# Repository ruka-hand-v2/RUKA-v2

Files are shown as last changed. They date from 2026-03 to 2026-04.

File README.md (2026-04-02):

<h1 align="center" style="font-size: 2.0em; font-weight: bold; margin-bottom: 0; border: none; border-bottom: none;">RUKA-v2: Tendon Driven Open-Source Dexterous Hand with Wrist and Abduction for Robot Learning</h1>

##### <p align="center"> [Xinqi Liu<sup>*2</sup>](https://www.linkedin.com/in/xinqi-liu-889256299/), [Ruoxi Hu<sup>*1</sup>](https://www.linkedin.com/in/sissi-h-013288321/), [Alejandro Ojeda Olarte<sup>1</sup>](https://aojedao.github.io/Portfolio/), [Zhuoran Chen<sup>2</sup>](https://www.linkedin.com/in/zhuoran-chen-90a18a251/), [Kenny Ma<sup>1</sup>](https://kmang0.github.io/KMAWeb/), [Charles Cheng Ji<sup>1</sup>](https://charlesji.com/), [Lerrel Pinto<sup>1</sup>](https://lerrelpinto.com), [Raunaq Bhirangi<sup>1</sup>](https://raunaqbhirangi.github.io/), [Irmak Guzey<sup>1</sup>](https://irmakguzey.github.io/)</p>
##### <p align="center"><sup>1</sup>New York University&emsp;<sup>2</sup>New York University Shanghai</p>
##### <p align="center"><sup>*</sup>Equal contribution</p>

<p align="center">
  
 </p>

#####
<div align="center">
     &ensp;
     &ensp; 
     &ensp;
    
</div>

#####

## Installation
Download the repo, create the conda environment, install requirements and install the `ruka_hand` package.
```
git clone --recurse-submodules https://github.com/ruka-hand-v2/RUKA-v2
cd RUKA-v2
conda env create -f environment.yml
conda activate ruka_hand
pip install -r requirements.txt
pip install -e .
```

### Connecting RUKA-v2
Connect the RUKA-v2 hand to your workstation using a USB cable. Then, identify which port the USB is connected to. You can do this by plugging and unplugging the hand while observing the changes in the output of `ls /dev/ttyUSB*`. The port that appears when you plug in the hand corresponds to that hand (left or right).
Update the `USB_PORTS` dictionary in `ruka_hand/utils/constants.py` accordingly, e.g., `USB_PORTS = {"left": "/dev/ttyUSB0", "right": "/dev/ttyUSB1"}`.

You can try moving the motors to the reset position by running:
```
python scripts/reset_motors.py --hand_type <right|left>
```
If this moves the intended hand then it means that the initial software is completed!

**NOTE:**
If you get an error saying that 
```
serial.serialutil.SerialException: [Errno 13] could not open port /dev/ttyUSB0: [Errno 13] Permission denied: '/dev/ttyUSB0'
```
You might need to run following commands to add your user to `dialout` group and reboot the machine for it to take effect.
```
sudo usermod -aG dialout $USER
sudo reboot
```

### Calibrating Motor Ranges
Since RUKA-v2 is a tendon-driven hand, cable tensions can vary between different builds. To ensure consistency across builds, we provide a calibration script that determines the motor ranges by finding the fully curled finger bound and the in-tension bound (finger is fully open and the tendon is in tension).
Run the following command to save the motor limits to `RUKA/motor_limits/<left|right>_<tension|curl>_limits.npy`:  
```
python calibrate_motors.py --hand-type <left|right>
```
These motor limits are later used in `ruka_hand/control/hand.py`.

During calibration, you will be prompted to move the joints individually using the ↑/↓ keys to increase or decrease the motor commands, and to press enter when a desired positon is reached. Make sure to identify which motor is moved and ensure that the string is tensioned when moving to the open position. 

When moving joints, we sometimes observe that the knuckle joints don't fully curl. If you notice this behavior (for example, the index finger not fully curling despite changing the motor command, please gently push the finger to complete the curl.

After running the calibration, execute `python scripts/reset_motors.py --hand-type <right|left>`. This should move the fingers to a fully open position, with the tendons tensioned but the fingers remaining extended.

## Teleoperation

We provide scripts to teleoperate RUKA-v2 using Mediapipe
 ```
  python teleop_mediapipe.py
  ```
And we provide controllers in `ruka_hand/control/controller_retarget.py` that can be used to teleoperate RUKA-v2 using the [Oculus headset](https://www.meta.com/quest/quest-3/). 

## Franka-Teach
We provide code for teleoperating the RUKA-v2 mounted on a 7-DOF Franka Arm with single arm and bimanual setups using Open-Teach in the submodules `franka-teach-single` and `franka-teach-bimanual`, please refer to documentation in the [Franka-Teach](https://github.com/pianapolataa/Franka-Teach/blob/main/README.md) submodules.

## BAKU
We provide code for training your own visual BC policy with RUKA-v2 using BAKU in the submodule `BAKU`. Please refer to documentation in the [BAKU](https://github.com/pianapolataa/BAKU/blob/main/Instructions.md) submodule.

## Attachable Encoders
For the attachable encoders setup and data collection, please see the [Attachable Encoders README](ruka_encoders/README.md).

**Quick Start Commands:**
```bash
python calibration/recalibrate_limits.py --serial-port /dev/ttyACM0 --hand right
python calibration/extract_filtered_limits.py
python data_collection/random_joint_generator.py --points-per-joint 15 --wait-time 1.5
```

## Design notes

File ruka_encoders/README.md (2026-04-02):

# RUKA Encoders (v2)

This directory contains the firmware, calibration tools, and data collection scripts for the magnetic angle sensors (AS5600) used on the RUKA hand. These tools are designed to map raw sensor readings to physical motor positions and analyze tracking performance.

---

## 📂 Directory Structure

### 1. [firmware/](firmware/)
Contains the code that runs on the microcontroller side to read the AS5600 sensors and stream data to a host PC.
- **`Microcontroller_AS5600.ino`**: Arduino/ESP32 firmware that reads multiple sensors via I2C using a TCA9548A multiplexer and outputs degree values over Serial.

### 2. [calibration/](calibration/)
Contains tools for defining the relationship between motor ticks and sensor degrees.
- **`recalibrate_limits.py`**: An interactive script that moves each motor to its limits and prompts for manual joint movement to capture absolute physical boundaries.
- **`extract_filtered_limits.py`**: Processes calibration logs to generate a statistical "Ground Truth" mapping in a json format.
- **`manually_filtered_paper_limits.json`**: The reference configuration file containing the finalized motor-to-sensor mappings and limit bounds.

### 3. [data_collection/](data_collection/)
Contains automated scripts for testing the sensors and capturing synchronized motor/sensor data.
- **`random_joint_generator.py`**: Executes a sequence of random movements for each joint within the safe bounds defined in the calibration JSON and creates a csv file with the motor and sensor data.

---

## ⚙️ Workflow & Usage

Follow these steps to set up and use the encoder system:

### Step 1: Flash the Firmware
Upload the [Microcontroller_AS5600.ino](firmware/Microcontroller_AS5600.ino) to your microcontroller. Ensure all sensors are connected via the I2C multiplexer as expected by the code.

### Step 2: Capture Physical Limits
Run the interactive calibration script to capture the range of motion for each joint:
```bash
python calibration/recalibrate_limits.py --serial-port /dev/ttyACM0 --hand right
```
*Note: This will save CSV logs and a preliminary JSON to the `recalibrate_limits_logs/` folder.*

### Step 3: Finalize the Mapping
Run the extractor on your calibration logs to generate a noise-filtered JSON reference:
```bash
python calibration/extract_filtered_limits.py
```
*Note: This will default to reading logs from calibration/recalibrate_limits_logs/ and outputting to calibration/manually_filtered_paper_limits.json.*

### Step 4: Run Automated Tests
Use the filtered JSON to run a bounded random movement sequence and log the tracking performance:
```bash
python data_collection/random_joint_generator.py --points-per-joint 15 --wait-time 1.5
```
*Note: This will default to using the JSON in calibration/ and saving new logs to data_collection/random_generator_logs/.*

---

## 🛠 Hardware Dependencies
- **Sensors**: AS5600 Magnetic Encoders and holders.
- **Robot**: RUKA v2 Hand.
- **Microcontroller**: ESP32 or Arduino ESP32.
- **I2C Multiplexer**: TCA9548A with Qwiic connectors.
- **Communication**: USB-C cable.

For hardware maintenance or sensor replacement instructions, refer to the [Disassembly.md](Disassembly.md) guide.

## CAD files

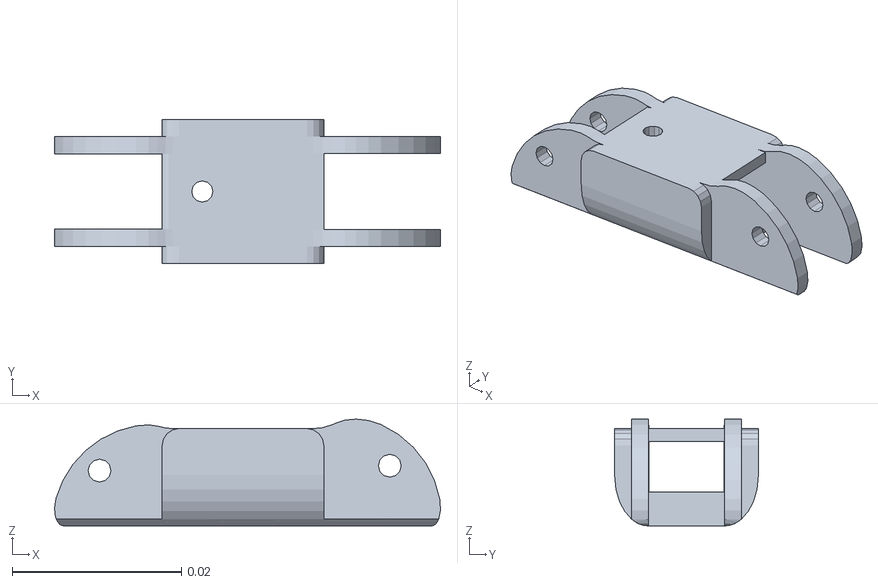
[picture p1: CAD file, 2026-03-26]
assets_v1/ruka/meshes/Middle_MCP.STL
0.0456 x 0.017 x 0.0126

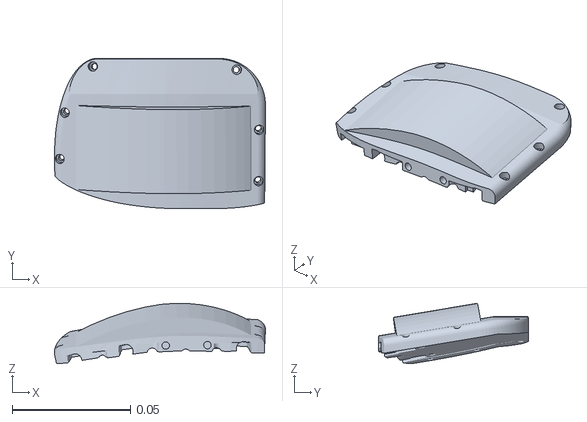
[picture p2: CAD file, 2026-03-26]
rukav2_sim/assets/backhand.stl
0.0891 x 0.0635 x 0.0255

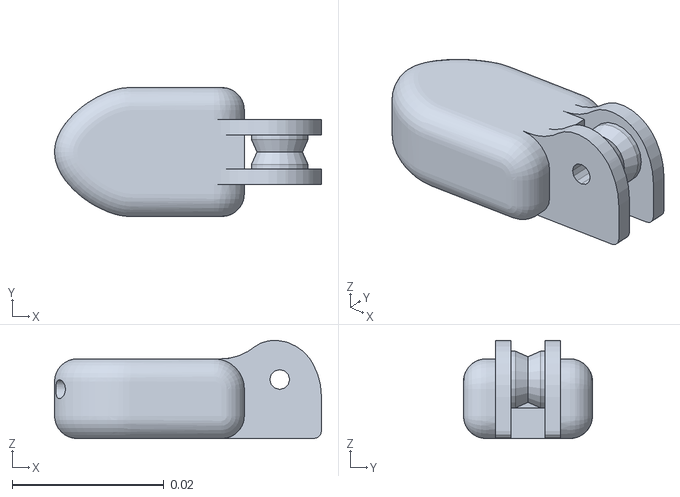
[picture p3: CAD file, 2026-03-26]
assets_v1/ruka/meshes/Index_PIP.STL
0.0352 x 0.017 x 0.0129

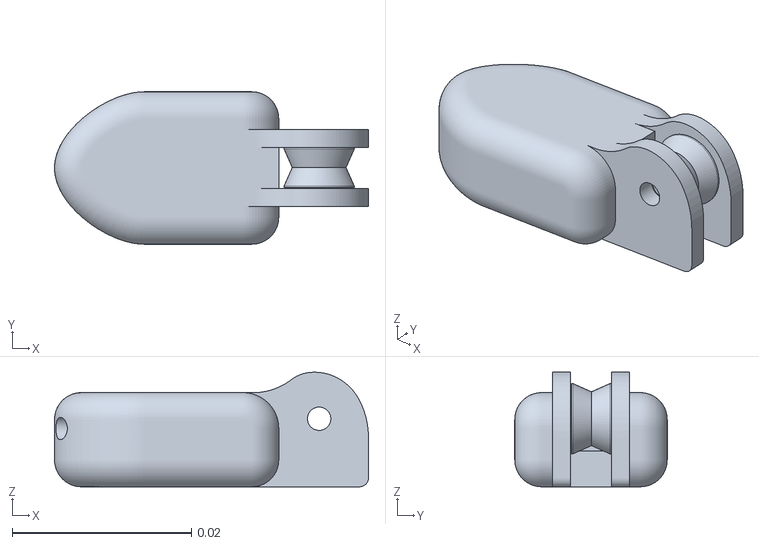
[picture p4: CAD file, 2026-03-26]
rukav2_sim/assets/finger___joint_3.stl
0.035 x 0.017 x 0.0128

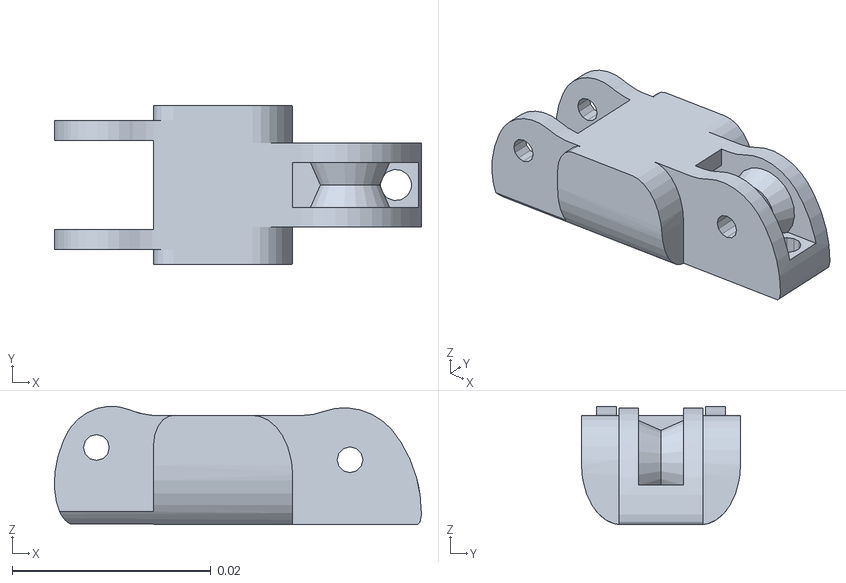
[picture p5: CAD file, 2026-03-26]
assets_v1/ruka/meshes/Index_DIP.STL
0.037 x 0.016 x 0.0119

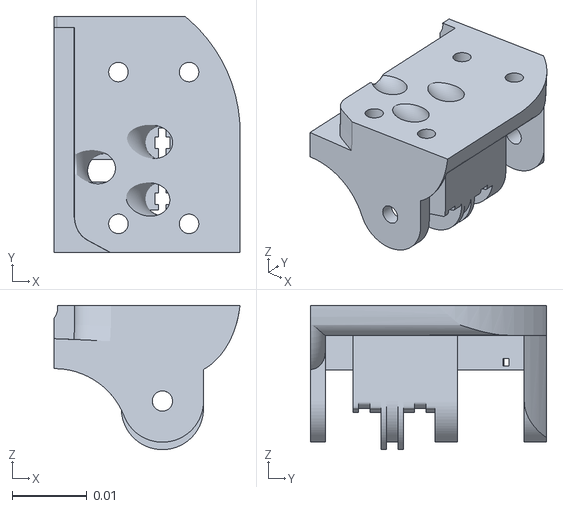
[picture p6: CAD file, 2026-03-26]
rukav2_sim/assets/thumb_attachment.stl
0.0249 x 0.0316 x 0.0193

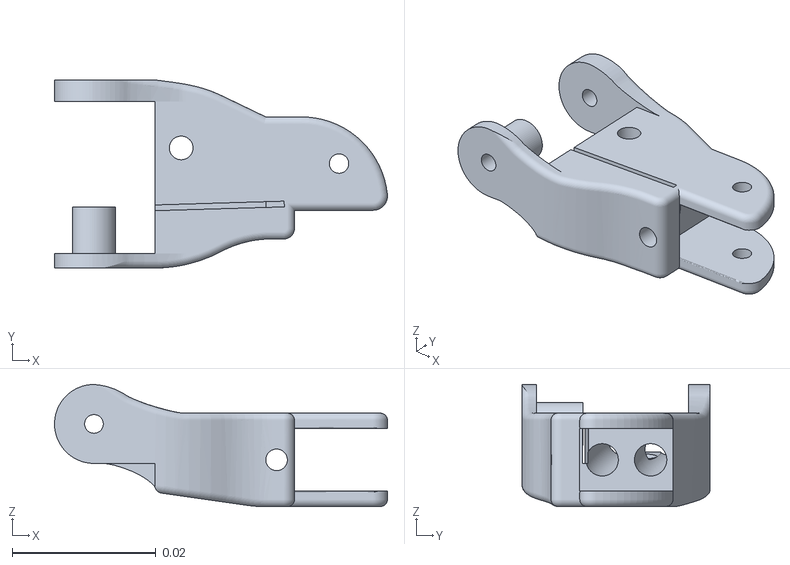
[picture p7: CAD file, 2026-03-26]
rukav2_sim/assets/thumb___joint_1.stl
0.0464 x 0.0262 x 0.017

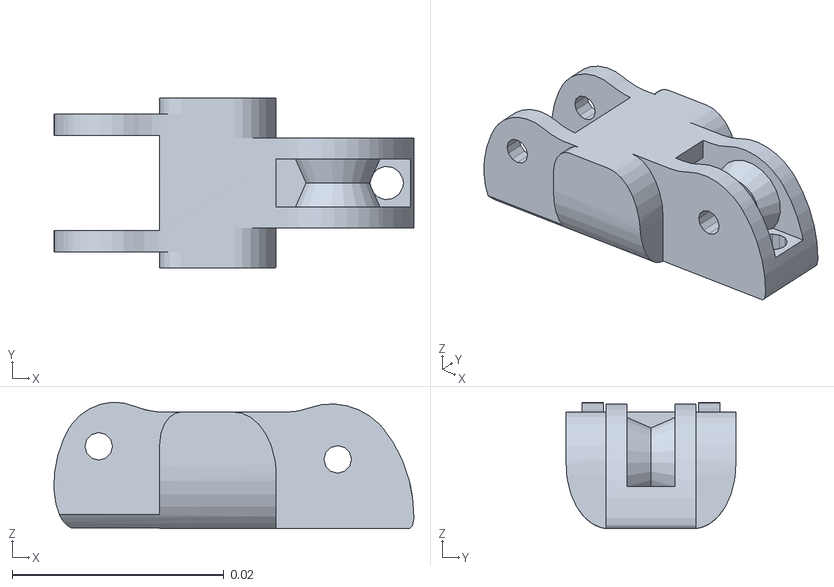
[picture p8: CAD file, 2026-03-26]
assets_v1/ruka/meshes/Pinky_DIP.STL
0.034 x 0.016 x 0.0119

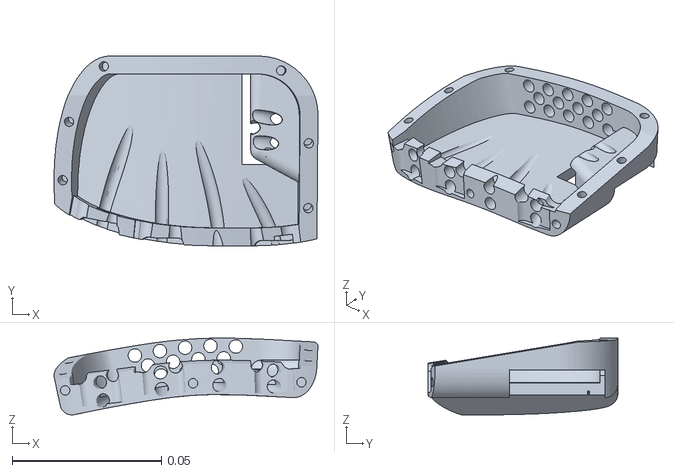
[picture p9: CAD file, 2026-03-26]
rukav2_sim/assets/palm.stl
0.0883 x 0.0635 x 0.0257

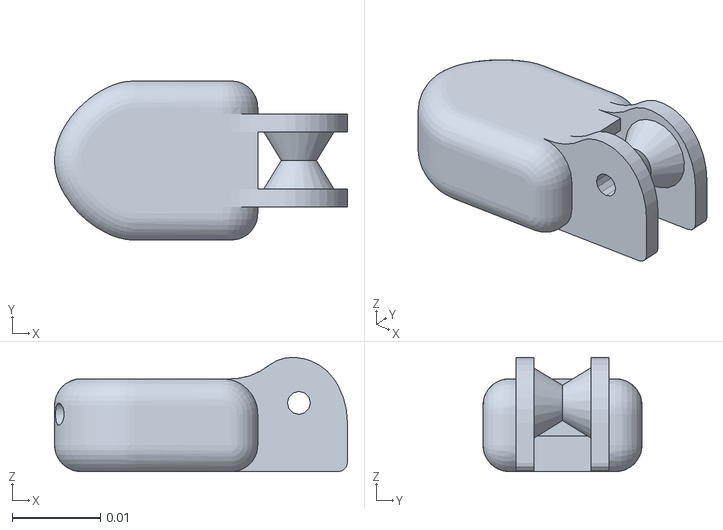
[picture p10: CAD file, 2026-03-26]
assets_v1/ruka/meshes/Thumb_PIP.STL
0.0332 x 0.018 x 0.0129

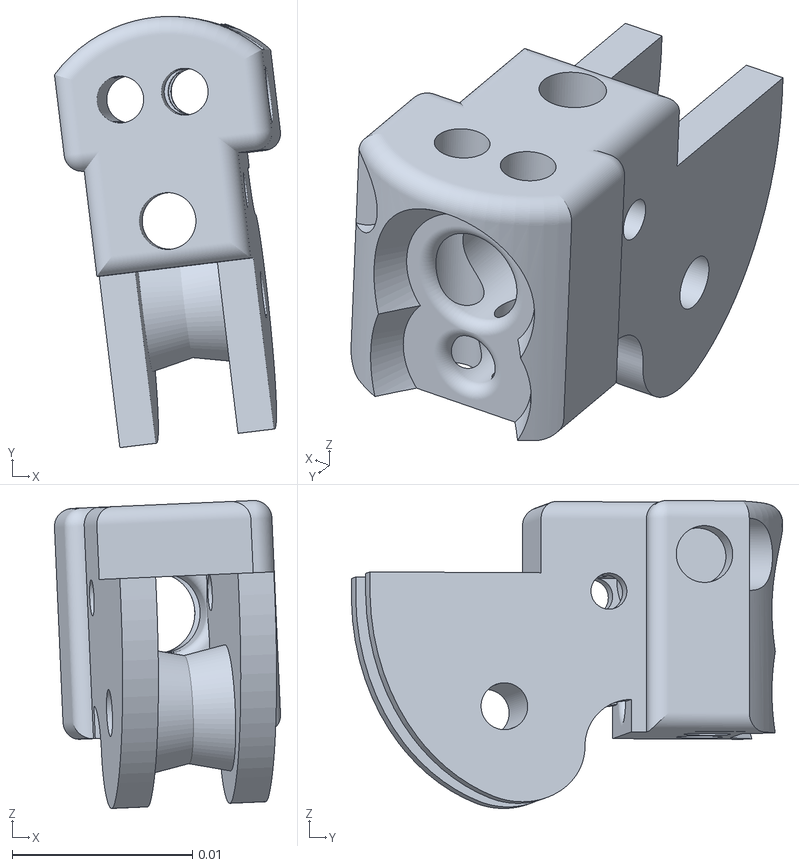
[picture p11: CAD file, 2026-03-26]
rukav2_sim/assets/knuclke_index_ext.stl
0.0125 x 0.0239 x 0.0171

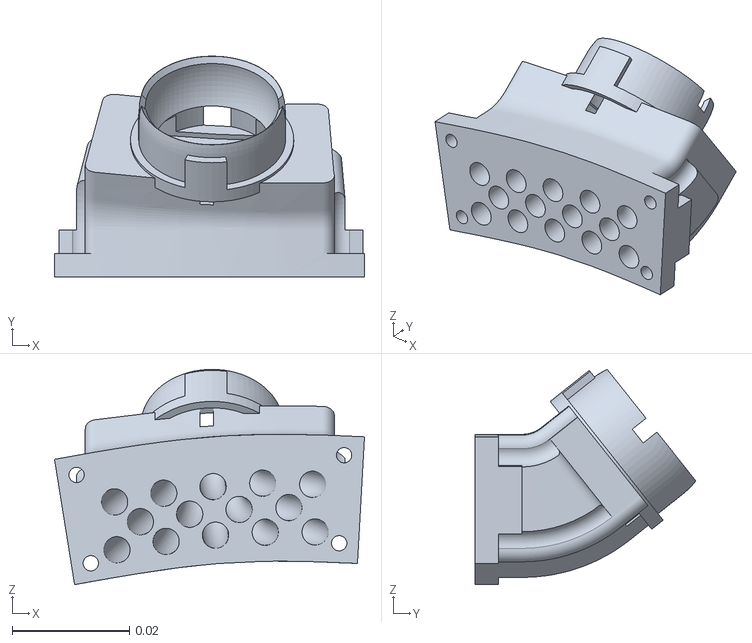
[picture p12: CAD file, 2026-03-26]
rukav2_sim/assets/wrist_connector_bend.stl
0.0528 x 0.0376 x 0.0367

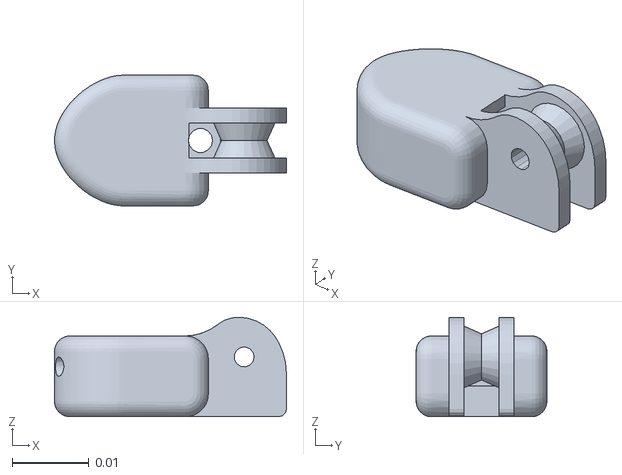
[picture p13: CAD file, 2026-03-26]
assets_v1/ruka/meshes/Pinky_PIP.STL
0.0302 x 0.017 x 0.0129

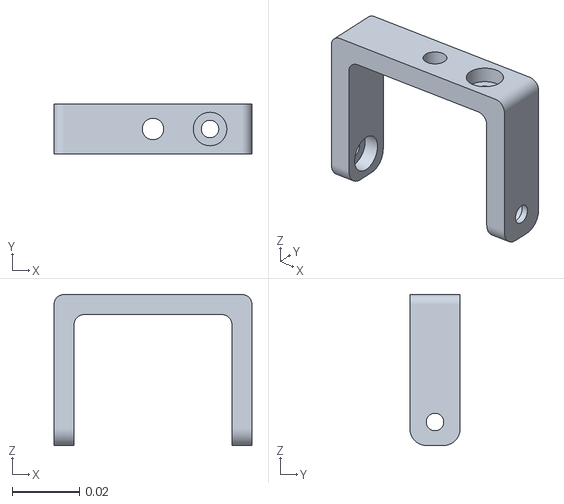
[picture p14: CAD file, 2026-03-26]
rukav2_sim/assets/inner.stl
0.059 x 0.015 x 0.045

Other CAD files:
assets_v1/ruka/meshes/Ring_MCP.STL
rukav2_sim/assets/mcp.stl
assets_v1/ruka/meshes/Middle_PIP.STL
assets_v1/ruka/meshes/Middle_DIP.STL
assets_v1/ruka/meshes/Index_MCP.STL
assets_v1/ruka/meshes/Palm.STL
assets_v1/ruka/meshes/Pinky_MCP.STL
assets_v1/ruka/meshes/Ring_DIP.STL
assets_v1/ruka/meshes/Ring_PIP.STL
assets_v1/ruka/meshes/Thumb_DIP.STL
assets_v1/ruka/meshes/Thumb_MCP.STL
rukav2_sim/assets/base_new.stl
rukav2_sim/assets/bearing_plate.stl
rukav2_sim/assets/cap.stl
rukav2_sim/assets/front_palm.stl
rukav2_sim/assets/knuckle_ring_ext.stl
rukav2_sim/assets/low_ball.stl
rukav2_sim/assets/outer.stl
rukav2_sim/assets/part_1.stl
rukav2_sim/assets/pinky___joint_2.stl
rukav2_sim/assets/pinky___joint_3.stl
rukav2_sim/assets/pip.stl
rukav2_sim/assets/thumb___joint_2.stl
rukav2_sim/assets/thumb___joint_3.stl

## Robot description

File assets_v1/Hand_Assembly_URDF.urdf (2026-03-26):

<?xml version="1.0" encoding="utf-8"?>
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
<robot name="Hand Assembly_URDF">
  <link name="Palm">
    <inertial>
      <origin xyz="0.00542702034628404 -0.0153261828960426 -0.00331775831735218" rpy="0 0 0" />
      <mass value="0.12595408931589" />
      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
    </inertial>
    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
  </link>
  <link name="Index_MCP_Link">
    <inertial>
      <origin xyz="0.0288723846218028 -1.28992836481712E-08 0.00378475045602162" rpy="0 0 0" />
      <mass value="0.00327912415799064" />
      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
    </inertial>
    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
  </link>
  <joint name="Index_MCP_Joint" type="revolute">
    <origin xyz="0.0322 0.0146007 -0.08022" rpy="2.5326 -1.3601 2.1257" />
    <parent link="Palm" />
    <child link="Index_MCP_Link" />
    <axis xyz="0 1 0" />
    <limit lower="0" upper="2.44222" effort="1" velocity="1" />
  </joint>
  <link name="Index_DIP_Link">
    <inertial>
      <origin xyz="0.000734413748040258 -1.34435329920274E-07 0.00333493475378864" rpy="0 0 0" />
      <mass value="0.00300529600906836" />
      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
    </inertial>
    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
  </link>
  <joint name="Index_DIP_Joint" type="revolute">
    <origin xyz="-0.035057 0 0.002" rpy="0 0.17453 0" />
    <parent link="Index_MCP_Link" />
    <child link="Index_DIP_Link" />
    <axis xyz="0 1 0" />
    <limit lower="0" upper="2.09" effort="1" velocity="1" />
  </joint>
  <link name="Index_PIP_Link">
    <inertial>
      <origin xyz="-0.0274082864999729 1.00210984628479E-07 0.00320314184184918" rpy="0 0 0" />
      <mass value="0.00356976709245697" />
      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
    </inertial>
    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
  </link>
  <joint name="Index_PIP_Joint" type="revolute">
    <origin xyz="-0.027 0.0045 0.001" rpy="0 0 0" />
    <parent link="Index_DIP_Link" />
    <child link="Index_PIP_Link" />
    <axis xyz="0 1 0" />
    <limit lower="0" upper="2.09" effort="1" velocity="1" />
  </joint>
  <link name="Middle_MCP_Link">
    <inertial>
      <origin xyz="0.0288723883673292 -9.49407751894837E-09 0.00378477344579253" rpy="0 0 0" />
      <mass value="0.00327911243246083" />
      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
    </inertial>
    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
  </link>
  <joint name="Middle_MCP_Joint" type="revolute">
    <origin xyz="0.01518 0.0135414 -0.081" rpy="-1.57079632 -1.57079632 0" />
    <parent link="Palm" />
    <child link="Middle_MCP_Link" />
    <axis xyz="0 1 0" />
    <limit lower="0" upper="2.44222" effort="1" velocity="1" />
  </joint>
  <link name="Middle_DIP_Link">
    <inertial>
      <origin xyz="0.000734411874024732 -1.31356892699858E-07 0.00333493692396733" rpy="0 0 0" />
      <mass value="0.0030052951603588" />
      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
    </inertial>
    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
  </link>
  <joint name="Middle_DIP_Joint" type="revolute">
    <origin xyz="-0.034 0 0" rpy="0 0 0" />
    <parent link="Middle_MCP_Link" />
    <child link="Middle_DIP_Link" />
    <axis xyz="0 1 0" />
    <limit lower="0" upper="2.09" effort="1" velocity="1" />
  </joint>
  <link name="Middle_PIP_Link">
    <inertial>
      <origin xyz="-0.0274082879981569 9.97468629377468E-08 0.0032031423234857" rpy="0 0 0" />
      <mass value="0.0035697679495293" />
      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
    </inertial>
    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
  </link>
  <joint name="Middle_PIP_Joint" type="revolute">
    <origin xyz="-0.026 0 0.002" rpy="0 0 0" />
    <parent link="Middle_DIP_Link" />
    <child link="Middle_PIP_Link" />
    <axis xyz="0 1 0" />
    <limit lower="0" upper="2.09" effort="1" velocity="1" />
  </joint>
  <link name="Ring_MCP_Link">
    <inertial>
      <origin xyz="0.0288723878014377 -7.11557345358695E-09 0.00378475517527948" rpy="0 0 0" />
      <mass value="0.00327912106977147" />
      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
    </inertial>
    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
  </link>
  <joint name="Ring_MCP_Joint" type="revolute">
    <origin xyz="-0.0088 0.01453 -0.08009" rpy="-1.2806 -1.4598 -0.34861" />
    <parent link="Palm" />
    <child link="Ring_MCP_Link" />
    <axis xyz="0 1 0" />
    <limit lower="0" upper="2.44222" effort="1" velocity="1" />
  </joint>
  <link name="Ring_DIP_Link">
    <inertial>
      <origin xyz="0.000734408991983959 -1.2934669113172E-07 0.00333493923161951" rpy="0 0 0" />
      <mass value="0.00300529389020819" />
      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
    </inertial>
    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
  </link>
  <joint name="Ring_DIP_Joint" type="revolute">
    <origin xyz="-0.036 0 0" rpy="0 0 0" />
    <parent link="Ring_MCP_Link" />
    <child link="Ring_DIP_Link" />
    <axis xyz="0 1 0" />
    <limit lower="0" upper="2.09" effort="1" velocity="1" />
  </joint>
  <link name="Ring_PIP_Link">
    <inertial>
      <origin xyz="-0.02740827895642 1.00945133223911E-07 0.00320314931394115" rpy="0 0 0" />
      <mass value="0.00356976241817527" />
      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
    </inertial>
    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
  </link>
  <joint name="Ring_PIP_Joint" type="revolute">
    <origin xyz="-0.025746 0 0" rpy="0 0 0" />
    <parent link="Ring_DIP_Link" />
    <child link="Ring_PIP_Link" />
    <axis xyz="0 1 0" />
    <limit lower="0" upper="2.09" effort="1" velocity="1" />
  </joint>
  <link name="Pinky_MCP_Link">
    <inertial>
      <origin xyz="0.0268917272607511 -2.13280075440914E-08 0.00337656502783252" rpy="0 0 0" />
      <mass value="0.00308278515475546" />
      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
    </inertial>
    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
  </link>
  <joint name="Pinky_MCP_Joint" type="revolute">
    <origin xyz="-0.030617 0.020313 -0.07398" rpy="-1.1404 -1.3618 -0.5566" />
    <parent link="Palm" />
    <child link="Pinky_MCP_Link" />
    <axis xyz="0 1 0" />
    <limit lower="0" upper="2.44222" effort="1" velocity="1" />
  </joint>
  <link name="Pinky_DIP_Link">
    <inertial>
      <origin xyz="0.000757211877111238 -1.38277174707019E-07 0.00329942828313" rpy="0 0 0" />
      <mass value="0.00260945166429854" />
      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
    </inertial>
    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
  </link>
  <joint name="Pinky_DIP_Joint" type="revolute">
    <origin xyz="-0.032 0 0" rpy="0 0.027735 0" />
    <parent link="Pinky_MCP_Link" />
    <child link="Pinky_DIP_Link" />
    <axis xyz="0 1 0" />
    <limit lower="0" upper="2.09" effort="1" velocity="1" />
  </joint>
  <link name="Pinky_PIP_Link">
    <inertial>
      <origin xyz="-0.0236575116359834 -8.70957672025052E-08 0.00338829472701592" rpy="0 0 0" />
      <mass value="0.0030687510852178" />
      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
    </inertial>
    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
  </link>
  <joint name="Pinky_PIP_Joint" type="revolute">
    <origin xyz="-0.023 0 0.001" rpy="0 0 0" />
    <parent link="Pinky_DIP_Link" />
    <child link="Pinky_PIP_Link" />
    <axis xyz="0 1 0" />
    <limit lower="0" upper="2.09" effort="1" velocity="1" />
  </joint>
  <link name="Thumb_MCP_Link">
    <inertial>
      <origin xyz="0.0162525772945904 -0.00468252056075796 0.00333968865411333" rpy="0 0 0" />
      <mass value="0.00526715244868984" />
      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
    </inertial>
    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
  </link>
  <joint name="Thumb_CMC_Joint" type="revolute">
    <origin xyz="0.037688 0.022225 -0.025118" rpy="-1.5708 0 0.031855" />
    <parent link="Palm" />
    <child link="Thumb_MCP_Link" />
    <axis xyz="0 -1 0" />
    <limit lower="0" upper="3.314" effort="1" velocity="1" />
  </joint>
  <link name="Thumb_DIP_Link">
    <inertial>
      <origin xyz="-0.000359156365804594 5.04339516718168E-05 0.00349653038903846" rpy="0 0 0" />
      <mass value="0.00330019814015192" />
      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
    </inertial>
    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
  </link>
  <joint name="Thumb_MCP_Joint" type="revolute">
    <origin xyz="0.033935 -0.0044094 -0.0065999" rpy="1.57079 0 3.1416" />
    <parent link="Thumb_MCP_Link" />
    <child link="Thumb_DIP_Link" />
    <axis xyz="0 1 0" />
    <limit lower="0" upper="1.57" effort="1" velocity="1" />
  </joint>
  <link name="Thumb_PIP_Link">
    <inertial>
      <origin xyz="-0.028210435039398 -4.96887226884846E-08 0.00319436851781224" rpy="0 0 0" />
      <mass value="0.00347336056393131" />
      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
    </inertial>
    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
  </link>
  <joint name="Thumb_IP_Joint" type="revolute">
    <origin xyz="-0.027794 0.0035 0.000007" rpy="-0.7854 0 0" />
    <parent link="Thumb_DIP_Link" />
    <child link="Thumb_PIP_Link" />
    <axis xyz="0 1 0" />
    <limit lower="0" upper="2.09" effort="1" velocity="1" />
  </joint>
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

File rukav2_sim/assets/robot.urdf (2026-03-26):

<?xml version="1.0" ?>
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
<robot name="folderv2">
  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
  <link name="base_new">
    <inertial>
      <origin xyz="-0.0029519 -0.0313554 0.00805561" rpy="0 0 0"/>
      <mass value="0.003"/>
      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
    </inertial>
    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
  </link>
  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
  <link name="outer">
    <inertial>
      <origin xyz="7.04841e-18 0.0210334 -0.0482655" rpy="0 0 0"/>
      <mass value="0.001"/>
      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
    </inertial>
    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
  </link>
  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
  <link name="backhand">
    <inertial>
      <origin xyz="-0.00992524 -0.0442501 -0.0432109" rpy="0 0 0"/>
      <mass value="0.006"/>
      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
    </inertial>
    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
  </link>
  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
  <link name="knuclke_index_ext">
    <inertial>
      <origin xyz="-0.00174312 -0.00118773 -0.00872925" rpy="0 0 0"/>
      <mass value="0.003"/>
      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
    </inertial>
    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
  </link>
  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
  <link name="mcp">
    <inertial>
      <origin xyz="-0.0167147 -0.00133536 0.00450002" rpy="0 0 0"/>
      <mass value="0.001"/>
      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
    </inertial>
    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
  </link>
  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
  <link name="pip">
    <inertial>
      <origin xyz="-0.0107299 0.000625775 -0.00445004" rpy="0 0 0"/>
      <mass value="0.001"/>
      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
    </inertial>
    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
  </link>
  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
  <link name="finger___joint_3">
    <inertial>
      <origin xyz="-0.0130533 -0.00240115 -0.00430199" rpy="0 0 0"/>
      <mass value="0.001"/>
      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
    </inertial>
    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
  </link>
  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
  <joint name="index_dip" type="revolute">
    <origin xyz="-0.0255 -0.000943294 -0.00875" rpy="-3.14159 5.32907e-15 -6.93889e-16"/>
    <parent link="pip"/>
    <child link="finger___joint_3"/>
    <mimic joint="index_pip" multiplier="1.0" offset="0"/>
    <axis xyz="0 0 -1"/>
    <limit effort="10" velocity="10" lower="0" upper="2.0944"/>
  </joint>
  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
  <joint name="index_pip" type="revolute">
    <origin xyz="-0.0342917 -0.000464732 5e-05" rpy="3.14159 -1.66533e-16 2.77556e-17"/>
    <parent link="mcp"/>
    <child link="pip"/>
    <axis xyz="0 0 1"/>
    <limit effort="10" velocity="10" lower="0" upper="1.91986"/>
  </joint>
  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
  <joint name="index_mcp" type="revolute">
    <origin xyz="-0.00744734 -0.00999639 -0.0134138" rpy="-1.5708 -0.536191 0.561167"/>
    <parent link="knuclke_index_ext"/>
    <child link="mcp"/>
    <axis xyz="0 0 -1"/>
    <limit effort="10" velocity="10" lower="0" upper="1.91986"/>
  </joint>
  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
  <joint name="index_splay" type="revolute">
    <origin xyz="-0.0371598 -0.0783979 -0.0780332" rpy="2.74947 -0.561588 2.06824"/>
    <parent link="backhand"/>
    <child link="knuclke_index_ext"/>
    <axis xyz="0 0 1"/>
    <limit effort="10" velocity="10" lower="-0.191799" upper="0.201799"/>
  </joint>
  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
  <link name="mcp_2">
    <inertial>
      <origin xyz="-0.0167147 0.00133536 0.00449998" rpy="0 0 0"/>
      <mass value="0.001"/>
      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
    </inertial>
    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
  </link>
  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
  <link name="pip_2">
    <inertial>
      <origin xyz="-0.0107299 -0.000625775 -0.00424996" rpy="0 0 0"/>
      <mass value="0.001"/>
      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
    </inertial>
    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
  </link>
  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
  <link name="finger___joint_3_2">
    <inertial>
      <origin xyz="-0.0130533 0.00240115 -0.00429801" rpy="0 0 0"/>
      <mass value="0.001"/>
      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
    </inertial>
    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
  </link>
  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
  <joint name="mid_dip" type="revolute">
    <origin xyz="-0.0255 0.000943294 -0.00855" rpy="3.14159 -1.47798e-14 -0.0381857"/>
    <parent link="pip_2"/>
    <child link="finger___joint_3_2"/>
     <mimic joint="mid_pip" multiplier="1.0" offset="0"/>
    <axis xyz="0 0 1"/>
    <limit effort="10" velocity="10" lower="0" upper="2.0944"/>
  </joint>
  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
  <joint name="mid_pip" type="revolute">
    <origin xyz="-0.0342917 0.000464732 0.00025" rpy="3.14159 -6.10623e-16 0.147354"/>
    <parent link="mcp_2"/>
    <child link="pip_2"/>
    <axis xyz="0 0 -1"/>
    <limit effort="10" velocity="10" lower="0" upper="1.91986"/>
  </joint>
  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
  <joint name="mid_mcp" type="revolute">
    <origin xyz="-0.0163656 -0.0982207 -0.0763958" rpy="-1.60501 -0.0577797 1.45284"/>
    <parent link="backhand"/>
    <child link="mcp_2"/>
    <axis xyz="0 0 1"/>
    <limit effort="10" velocity="10" lower="-0.2" upper="1.91986"/>
  </joint>
  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
  <link name="knuckle_ring_ext">
    <inertial>
      <origin xyz="-0.00174313 -0.00118772 0.00672924" rpy="0 0 0"/>
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

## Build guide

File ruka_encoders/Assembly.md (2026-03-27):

# RUKA Hand Sensor Assembly Guide

This document outlines the step-by-step procedure for safely assembling the magnetic encoders and sensor holders back onto the RUKA hand. This is the inverse of the [Disassembly.md](Disassembly.md) process.

---

## 1. Thumb Sensors (Wrist to Tip)
The thumb sensors should be reinstalled starting from the base:

### Thumb CMC
- Slide the CMC holder up from the wrist area into its designated position.
- Secure it using the two screws on the bottom of the wrist:
    - **Inner Screw**: Tighten with a standard screwdriver.
    - **Outer Screw**: Tighten with an Allen key.

### Thumb MCP
- Slide the MCP holder onto the joint assembly.
- Fasten it securely by tightening the **nut** at the bottom of the holder.

### Thumb DIP
- Follow the same logic as the Index DIP: Slide the holder onto the joint, ensure the magnet is seated in its pin, and insert the 3D-printed securing part.
- Reattach the tensioning springs and tighten the screws.

---

## 2. Index Abduction Sensor
- Ensure the magnet cap is placed inside the frame slot (or inside the holder).
- Slide the abduction sensor holder into its slot near the base of the index finger.
- Tighten the single securing screw visible from the top of the hand frame.

---

## 3. Index Finger Sensors (MCP to DIP)
The index finger assembly requires careful alignment of pins and magnets:

1. **Relieve Frame Tension**: Temporarily loosen or remove the springs and pins if the frame is too tight to allow the holders to slide on.
2. **MCP Installation**:
   - Slide the MCP sensor holder onto the joint (this is a tight fit and may require force).
   - Position the magnet into the pin (use pliers if necessary to guide it until it snaps into place).
3. **DIP Installation**:
   - Slide the DIP sensor holder onto the tip joint.
   - Insert the small circular magnet holder onto the pin.
   - Slide the 3D-printed securing part in to lock the assembly.
4. **Finalize Index Frame**:
   - Ensure all pins are fully seated.
   - Tighten the outer-most screw on the MCP section.
   - Re-hook the **DIP** and **PIP** springs and tighten their securing screws to restore finger tension.

---

## 4. Electronics Reintegration
- **Mount Multiplexer**: Place the red TCA9548A I2C multiplexer board back onto the rear of the hand.
- **Connect Qwiic Cables**: Plug the Qwiic cables from the multiplexer into each sensor according to the following mapping (based on the calibration JSON):

| Mux Port | Sensor Name | Joint Type |
| :---: | :--- | :--- |
| **0** | Index Abduction | Base |
| **1** | Index DIP | Tip |
| **2** | Index PIP | Middle |
| **3** | Index MCP | Knuckle |
| **4** | Thumb CMC | Base |
| **5** | Thumb MCP | Middle |
| **6** | Thumb DIP | Tip |

- *Tip: Ensure the cables are routed cleanly to avoid interference with the joint movements.*
- **USB Connection**: Connect the USB-C cable from the ESP32/microcontroller to your host PC for testing.

---

## 5. Verification
After assembly, run the following to verify sensor readings:
1. Open the [Microcontroller_AS5600.ino](firmware/Microcontroller_AS5600.ino) in the Arduino IDE to check the Serial Monitor.
2. Run a calibration test to ensure all sensors are tracking correctly.

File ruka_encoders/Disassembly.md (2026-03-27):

# RUKA Hand Sensor Disassembly Guide

This document outlines the step-by-step procedure for safely disassembling the magnetic encoders and sensor holders from the RUKA hand.

---

## 1. Initial Preparation
Before touching the mechanical components, clear the electronics and cabling:
- **Disconnect Qwiic Cables**: Carefully unplug the Qwiic cables from every sensor.
- **Remove Multiplexer**: Unscrew and remove the red I2C multiplexer board from the back of the hand.

---

## 2. Index Finger Sensors (DIP, PIP, MCP)
The assembly for the Index finger is interconnected by tension and pins. Follow this order:

1. **Relieve Tension**: Remove the screws holding the springs for the **DIP** and **PIP** joints.
2. **Loosen MCP**: Remove the outer-most screw on the MCP section of the index finger.
3. **DIP Extraction**:
   - Push the DIP sensor slightly backward.
   - Remove the small circular holder on the pin (this secures the magnet).
   - Extract the 3D-printed part, then slide the sensor holder out. 
   - *Note: If the pin prevents the holder from sliding, use **pliers** to remove the pin first.*
4. **MCP Extraction**:
   - Reach the magnet in the next pin. If it is difficult to grasp, use **pliers**.
   - Loosen the magnet from the pin (it will likely attach itself to the sensor once free).
   - Slide the MCP sensor holder outward. 
   - *Note: This part is tight and may require significant force to slide off.*
5. **Reassembly of Frame**: Once holders are removed, replace the springs, screws, and pins to maintain the finger's structural integrity.

---

## 3. Index Abduction Sensor
The abduction sensor is a self-contained unit located near the base of the index finger:

1. **Unscrew**: Locate the single screw visible from the top of the hand and remove it.
2. **Slide**: Slide the holder out of its slot. 
3. **Magnet Cap**: A small magnet holder/cap may fall out during this step. Replace this cap (with the magnet inside) and re-fasten the screw after the main sensor holder has been removed.

---

## 4. Thumb Sensors
The thumb sensors are removed starting from the tip and moving toward the wrist:

### Thumb DIP
- Follow the same process as the index DIP: Unscrew the tensioners, slide the holder off the joint, and release the sensor.

### Thumb MCP
- This joint is easier to manage: Simply remove the **nut** located at the bottom of the holder.
- Slide the holder directly off the assembly.

### Thumb CMC
- The CMC holder is secured at two points on the bottom of the wrist.
- **Inner Screw**: This can be reached with a standard **screwdriver**.
- **Outer Screw**: Due to the angle, you may need an **Allen key** to reach this point.
- Release both screws, slide the holder down toward the arm, and replace the screws into the frame for safekeeping.

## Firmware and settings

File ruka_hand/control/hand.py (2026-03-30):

import os
from copy import deepcopy as copy

import numpy as np

from ruka_hand.utils.constants import (
    FINGER_NAMES_TO_MOTOR_IDS,
    MOTOR_RANGES_LEFT,
    MOTOR_RANGES_RIGHT,
    USB_PORTS,
)
from ruka_hand.utils.dynamixel_util import *
from ruka_hand.utils.file_ops import get_repo_root


# PID Gains
MCP_D_GAIN = 1000
MCP_I_GAIN = 500
MCP_P_GAIN = 2500

DIP_PIP_D_GAIN = 960
DIP_PIP_I_GAIN = 300
DIP_PIP_P_GAIN = 700


class Hand:
    """Robot Hand class.
    Initializes dynamixel client, sets motor ids and initial motor settings.
    """

    def __init__(self, hand_type="right"):
        if hand_type == "v1_right":
            self.motors = motors = [1, 2, 3, 4, 5, 6, 7, 8, 9, 10, 11]
            self.DIP_PIP_motors = [1, 2, 3, 5, 8, 10]
            self.MCP_motors = [0, 4, 6, 7, 9]
        else:
            self.motors = motors = [1, 2, 3, 4, 5, 6, 7, 8, 9, 10, 11, 12, 13, 14, 15, 16]
            self.DIP_PIP_motors = [14, 12, 7, 10, 6, 3]
            self.MCP_motors = [8, 9, 11, 4, 5, 2, 1, 15, 16, 13]
        self.port = USB_PORTS[hand_type]
        print(self.port, hand_type)
        self.dxl_client = DynamixelClient(motors, self.port)
        self.dxl_client.connect()

        self.fingers_dict = FINGER_NAMES_TO_MOTOR_IDS

        # Paramaters for initalization
        self.hand_type = hand_type
        self.curr_lim = 1300
        self.temp_lim = 60
        self.goal_velocity = 400
        self.operating_mode = 5  # 5: current-based position control
        # self.operating_mode = 3  # 5: current-based position control

        repo_root = get_repo_root()
        curled_path = os.path.join(repo_root, "curl_limits", f"{hand_type}_curl_limits.npy")
        tension_path = os.path.join(repo_root, "curl_limits", f"{hand_type}_tension_limits.npy")
        print(curled_path)
        if os.path.exists(curled_path) and os.path.exists(tension_path):
            print(f"Loading saved calibration for {hand_type}...")
            self.curled_bound = np.load(curled_path)
            self.tensioned_pos = np.load(tension_path)
        else:
            if hand_type == "right":
                self.curled_bound = np.array([2609, 2852, 1375, 1811, 2605, 2026, 1511, 1187, 354, 2184, 1969, 506, 2241, 1795, 1617, 1850])
                self.tensioned_pos = np.array([3500,3283, 2511, 1550, 3461, 897, 2590, 1371, 1047, 1400, 962, 930, 2980, 2340, 2417, 1400])
            elif hand_type == "left":
                self.curled_bound = np.array([1572, 2919, 1616, 3013, 3157, 2340, 1034, 1757, 3502, 1159, 511, 1952, 2170, 3380, 3204, 1338])
                self.tensioned_pos = np.array([1040, 2581, 660, 3947, 2973, 2814, 746, 1070, 3364, 1582, 1502, 1800, 1864, 2496, 2601, 1927])
            elif hand_type == "v1_right":
                self.curled_bound = np.array([2416, 3327, 2435, 986, 1248, 2939, 1950, 2808, 2077, 1893, 2230])
                self.tensioned_pos = np.array([3225, 3794, 2682, 1818, 1932, 3815, 2608, 3390, 3059, 2708, 3208])

        self.min_lim = np.minimum(self.tensioned_pos, self.curled_bound)
        self.max_lim = np.maximum(self.tensioned_pos, self.curled_bound) 

        self.init_pos = copy(self.tensioned_pos)
        self._commanded_pos = copy(self.tensioned_pos)

        # Initialization settings of dxl_client
        self.dxl_client.sync_write(
            motors,
            np.ones(len(motors)) * self.operating_mode,
            ADDR_OPERATING_MODE,
            LEN_OPERATING_MODE,
        )  # Set all motors to current-based position control mode
        self.dxl_client.sync_write(
            motors,
            np.ones(len(motors)) * self.temp_lim,
            ADDR_TEMP_LIMIT,
            LEN_TEMP_LIMIT,
        )  # Set Temp limit
        self.dxl_client.sync_write(
            motors,
            np.ones(len(motors)) * self.curr_lim,
            ADDR_CURRENT_LIMIT,
            LEN_CURRENT_LIMIT,
        )  # Set Current limit
        self.dxl_client.sync_write(
            FINGER_NAMES_TO_MOTOR_IDS["Thumb"],
            np.ones(len(motors)) * 700,
            ADDR_CURRENT_LIMIT,
            LEN_CURRENT_LIMIT,
        )  # Set thumb specific current limit
        self.dxl_client.sync_write(
            motors,
            np.ones(len(motors)) * self.goal_velocity,
            ADDR_GOAL_VELOCITY,
            LEN_GOAL_VELOCITY,
        )  # Set Goal Velocity

        # PID Gains for DIP + PIP motors
        self.dxl_client.sync_write(
            self.DIP_PIP_motors,
            np.ones(len(motors)) * DIP_PIP_P_GAIN,
            ADDR_POSITION_P_GAIN,
            LEN_POSITION_P_GAIN,
        )  # Set P gain for DIP and PIP motors
        self.dxl_client.sync_write(
            self.DIP_PIP_motors,
            np.ones(len(motors)) * DIP_PIP_I_GAIN,
            ADDR_POSITION_I_GAIN,
            LEN_POSITION_I_GAIN,
        )  # Set I gain for DIP and PIP motors
        self.dxl_client.sync_write(
            self.DIP_PIP_motors,
            np.ones(len(motors)) * DIP_PIP_D_GAIN,
            ADDR_POSITION_D_GAIN,
            LEN_POSITION_D_GAIN,
        )  # Set D gain for DIP and PIP motors

        # PID Gains for MCP motors
        self.dxl_client.sync_write(
            self.MCP_motors,
            np.ones(len(motors)) * MCP_P_GAIN,
            ADDR_POSITION_P_GAIN,
            LEN_POSITION_P_GAIN,
        )  # Set P gain for MCP motors

        # PID Gains for MCP motors
        self.dxl_client.sync_write(
            [9],
            [2000],
            ADDR_POSITION_P_GAIN,
            LEN_POSITION_P_GAIN,
        )  

        self.dxl_client.sync_write(
            self.MCP_motors,
            np.ones(len(motors)) * MCP_I_GAIN,
            ADDR_POSITION_I_GAIN,
            LEN_POSITION_I_GAIN,
        )  # Set I gain for MCP motors
        self.dxl_client.sync_write(
            self.MCP_motors,
            np.ones(len(motors)) * MCP_D_GAIN,
            ADDR_POSITION_D_GAIN,
            LEN_POSITION_D_GAIN,
        )  # Set D gain for MCP motors

        # Enable Torque
        self.dxl_client.set_torque_enabled(True, -1, 0.05)

        # self.dxl_client.set_pos(self.init_pos)

        self.data_recording_functions = {
            "actual_hand_state": self.get_hand_state,
            "commanded_hand_state": self.get_commanded_hand_state,
        }

    def close(self):
        self.dxl_client.disconnect()

    # read any given address for the given motors
    def read_any(self, addr: int, size: int):
        return self.dxl_client.sync_read(self.motors, addr, size)

    # read position
    def read_pos(self):
        # print(f"in read_pos")
        curr_pos = self.dxl_client.read_pos()
        while curr_pos is None:
            curr_pos = self.dxl_client.read_pos()
            time.sleep(0.001)

        return curr_pos

    # read velocity
    def read_vel(self):
        # print(f"in read_vel")
        return self.dxl_client.read_vel()

    # read current
    def read_cur(self):
        return self.dxl_client.read_cur()

    # set pose
    def set_pos(self, pos):
        self._commanded_pos = pos
        self.dxl_client.set_pos(pos)
        return

    def read_temp(self):
        self.dxl_client.sync_read(self.motors, 146, 1)

    @property
    def commanded_pos(self):
        return self._commanded_pos

    @property
    def actual_pos(self):
        pos = self.read_pos()
        while any(item is None for item in pos):
            pos = self.read_pos()
            time.sleep(0.0001)
        return pos

    def get_hand_state(self):

        motor_state = dict(
            position=np.array(self.actual_pos, dtype=np.float32),
            commanded_position=np.array(self.commanded_pos, dtype=np.float32),
            velocity=np.array(self.read_vel(), dtype=np.float32),
            timestamp=time.time(),
        )
        return motor_state

    def get_commanded_hand_state(self):

        motor_state = dict(
            position=np.array(self.commanded_pos, dtype=np.float32),
            timestamp=time.time(),
        )
        return motor_state

    def read_single_cur(self, motor_id):
        cur = self.dxl_client.read_single_cur(motor_id)
        return cur

if __name__ == "__main__":
    hand= Hand("left")

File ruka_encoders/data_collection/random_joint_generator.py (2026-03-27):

"""random_joint_generator.py
==========================
Loads the strictly filtered paper limits JSON, bounds the hand movements,
and executes sequential random commanded positions one joint at a time.

Usage Example:
--------------
To test every joint sequentially with 5 random points each, 
waiting 8.0 seconds between taking a reading, run:

    python random_joint_generator.py --points-per-joint 5 --wait-time 8.0

(If left blank, it defaults to 5 points and 5.0 seconds).
"""

import argparse
import csv
import json
import os
import random
import re
import sys
import threading
import time
from datetime import datetime
from pathlib import Path

# ── 0. Path Resolution ───────────────────────────────────────────────────────
SCRIPT_DIR   = os.path.dirname(os.path.abspath(__file__))
# Find project root (one level up from data_collection)
PROJECT_ROOT = os.path.dirname(SCRIPT_DIR)
# Path to the shared calibration JSON
DEFAULT_JSON_PATH = os.path.join(PROJECT_ROOT, "calibration", "manually_filtered_paper_limits.json")
# Default output directory relative to this script
DEFAULT_OUT_DIR = os.path.join(SCRIPT_DIR, "random_generator_logs")

import numpy as np
import serial

try:
    from ruka_hand.control.hand import Hand
except ImportError:
    Hand = None

N_SENSORS = 7
N_MOTORS = 16

OPEN_POS = [3559, 2864, 2247, 1891, 3407, 849, 2983, 1641, 1249, 853, 230, 1060, 3042, 2288, 2000, 1850]

# -------------------------------------------------------------------------
# Interpolation Math
# -------------------------------------------------------------------------
def expected_angle_from_json(limits_map: dict, motor_id: int, tick: float) -> float:
    if not np.isfinite(tick):
        return float("nan")
        
    for s_idx, config in limits_map.items():
        if config["motor_id"] == motor_id:
            c_min = float(config["commanded_min_ticks"])
            c_max = float(config["commanded_max_ticks"])
            d_min = float(config["filtered_sensor_min_deg"])
            d_max = float(config["filtered_sensor_max_deg"])
            
            span_ticks = c_max - c_min
            if span_ticks == 0:
                return float("nan")
                
            # Linear interpolation matching the bounds strictly defined in the JSON
            # Handles inversions automatically based on the mapping!
            norm = (float(tick) - c_min) / span_ticks
            return d_min + norm * (d_max - d_min)

    # Not found in JSON model
    return float("nan")

def _parse_sensor_line(line: str) -> dict[int, dict[str, float | int]] | None:
    line = line.strip()
    if not line or line.startswith("["):
        return None
    out = {}
    matches_with_raw = re.findall(r"S(\d+)\s*:\s*([-+]?\d*\.?\d+)\s*:\s*(-?\d+)", line)
    for s_str, deg_str, raw_str in matches_with_raw:
        out[int(s_str)] = {"deg": float(deg_str), "raw": int(raw_str)}
    if out:
        return out
    matches_deg_only = re.findall(r"Sensor(\d+)\s*:\s*([-+]?\d*\.?\d+)", line)
    for s_str, deg_str in matches_deg_only:
        out[int(s_str)] = {"deg": float(deg_str), "raw": -1}
    return out if out else None

# -------------------------------------------------------------------------
# Thread-safe Logger
# -------------------------------------------------------------------------
class RandomSequenceLogger:
    def __init__(self, serial_port: str, baud: int, hand: Hand, io_lock: threading.Lock, limits: dict):
        self.conn = serial.Serial(serial_port, baud, timeout=0.2)
        time.sleep(1.0)
        self.conn.reset_input_buffer()
        self.hand = hand
        self.io_lock = io_lock
        self.limits = limits
        
        self.stop_event = threading.Event()
        self.log_data = []
        self.t0 = 0.0
        
        self.lock = threading.Lock()
        self.current_cmd = OPEN_POS.copy()
        self.current_phase = "init"
        
        self.thread = threading.Thread(target=self._loop, daemon=True)
        
    def start(self):
        self.t0 = time.time()
        self.conn.write(b"s") # ensure streaming
        self.thread.start()
        
    def stop(self):
        self.stop_event.set()
        self.thread.join()
        try:
            self.conn.write(b"s")
            self.conn.close()
        except Exception:
            pass
            
    def set_command_state(self, cmd_pos, phase_name):
        with self.lock:
            self.current_cmd = cmd_pos.copy()
            self.current_phase = phase_name
            
    def _loop(self):
        while not self.stop_event.is_set():
            try:
                line = self.conn.readline().decode(errors="ignore")
                parsed = _parse_sensor_line(line)
            except Exception:
                parsed = None
                
            if parsed is None:
                continue
                
            t_rel = time.time() - self.t0
            
            actual_pos = [-1] * N_MOTORS
            if self.hand is not None:
                try:
                    with self.io_lock:
                        p = self.hand.read_pos()
                    if p:
                        actual_pos = [int(x) if x is not None else -1 for x in p[:N_MOTORS]]
                except Exception:
                    pass
            
            with self.lock:
                cmd_pos = self.current_cmd.copy()
                phase = self.current_phase
            
            # Predict angles perfectly derived right off the JSON boundaries
            cmd_angles = []
            act_angles = []
            for i in range(N_MOTORS):
                m_id = i + 1
                cmd_angles.append(expected_angle_from_json(self.limits, m_id, cmd_pos[i]))
                act_angles.append(expected_angle_from_json(self.limits, m_id, actual_pos[i]))
                
            deg_vals = [float("nan")] * N_SENSORS
            for s in range(N_SENSORS):
                if s in parsed:
                    deg_vals[s] = parsed[s]["deg"]
                    
            self.log_data.append({
                "t_rel": t_rel,
                "phase": phase,
                "commanded": cmd_pos,
                "actual": actual_pos,
                "cmd_angles": cmd_angles,
                "act_angles": act_angles,
                "deg": deg_vals
            })

# -------------------------------------------------------------------------
# Interp & Main
# -------------------------------------------------------------------------
def move_interpolated(hand, io_lock, start_pos, end_pos, steps=40, sleep_dt=0.01):
    for i in range(1, steps + 1):
        alpha = i / float(steps)
        cmd = [int(start_pos[j] * (1 - alpha) + end_pos[j] * alpha) for j in range(len(start_pos))]
        if hand is not None:
            with io_lock:
                hand.set_pos(cmd)
        time.sleep(sleep_dt)
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

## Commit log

2026-03-26 Added sim code
    [backhand.stl, base_new.stl, bearing_plate.stl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]
2026-03-30 add calibration code
2026-03-30 Update README with installation and calibration
    Added installation instructions and calibration steps for RUKA hand.
2026-03-31 changed calibration file
2026-03-31 Update calibration instructions in README
    Clarified calibration instructions and added notes on joint movement behavior.
2026-04-02 Updated encoder instructions in readme
2026-04-19 removed our builds motor limits
